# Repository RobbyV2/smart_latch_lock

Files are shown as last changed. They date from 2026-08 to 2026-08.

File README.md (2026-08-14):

# Folding-Arc Bike Lock

A self-closing bike lock built as a clamshell ring. A fixed arc bolts to the housing, a hinged arc swings 180 degrees to meet it, and a worm gearmotor closes the loop around the frame and rim on a button press or a BLE command. A spring latch pin seats with power off, a keyed cam lock covers a dead battery, and an ESP32-C3 on a 4-layer PCB runs the state machine.

<table>
<tr>
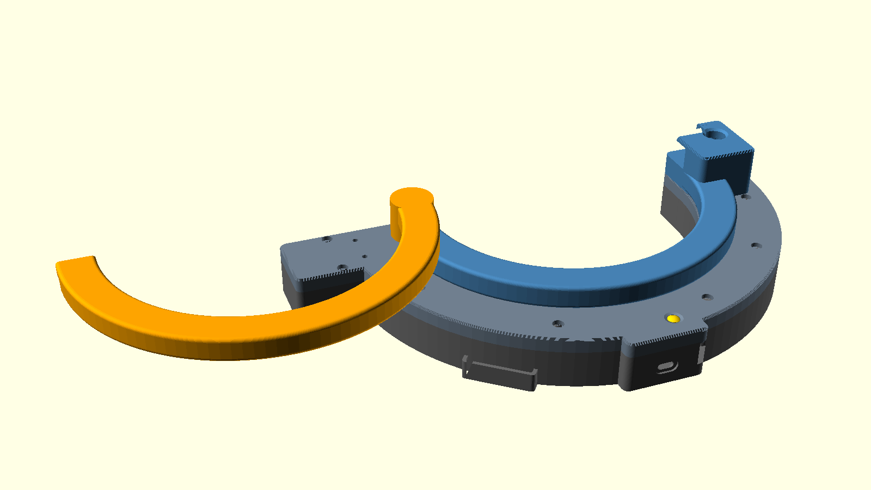
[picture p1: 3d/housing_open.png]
Housing with the swing arc folded open and the latch pin retracted
<td></td>
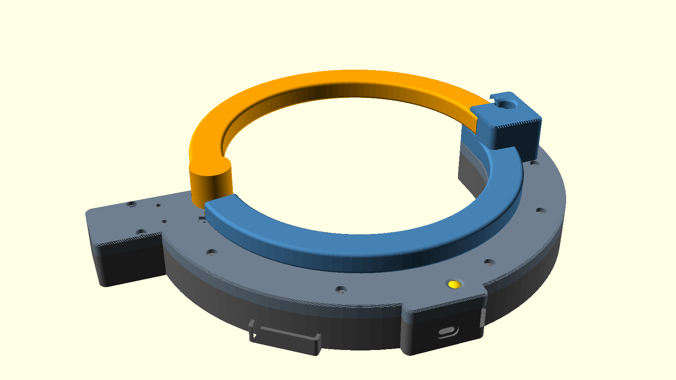
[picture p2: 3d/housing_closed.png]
Housing with the swing arc closed and the latch pin seated
<td></td>
</tr>
</table>

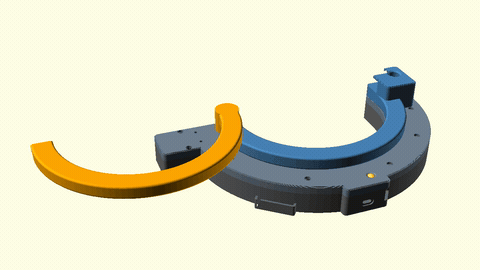
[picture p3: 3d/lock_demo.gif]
Animated lock cycle


The animation shows one closing cycle: the swing arc starts folded open and sweeps around until it seats in the receiver at the fixed arc tip.

<table>
<tr>
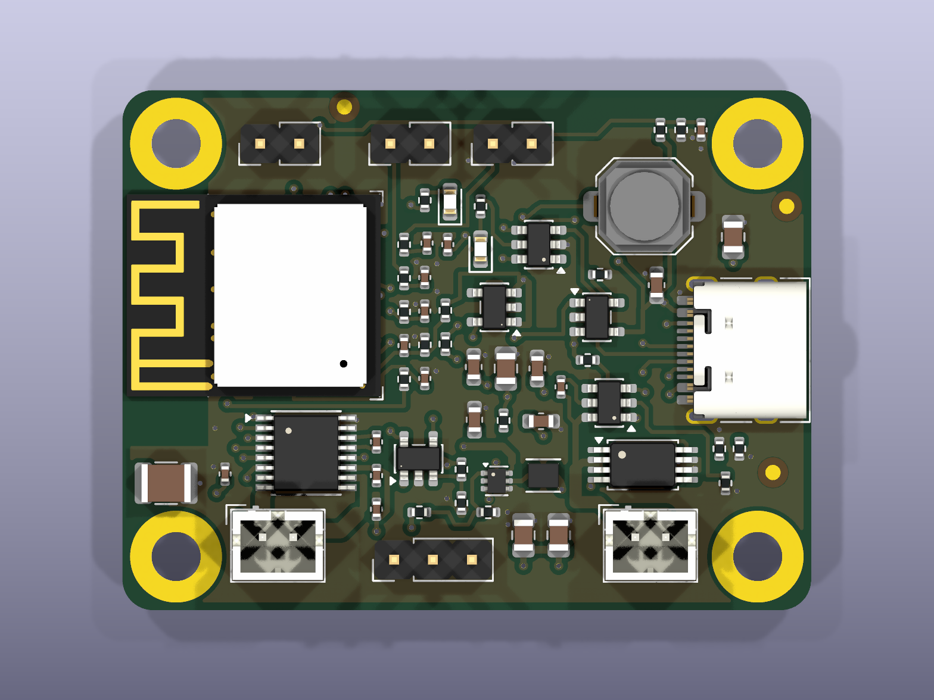
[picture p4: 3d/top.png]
Top view of the board
<td></td>
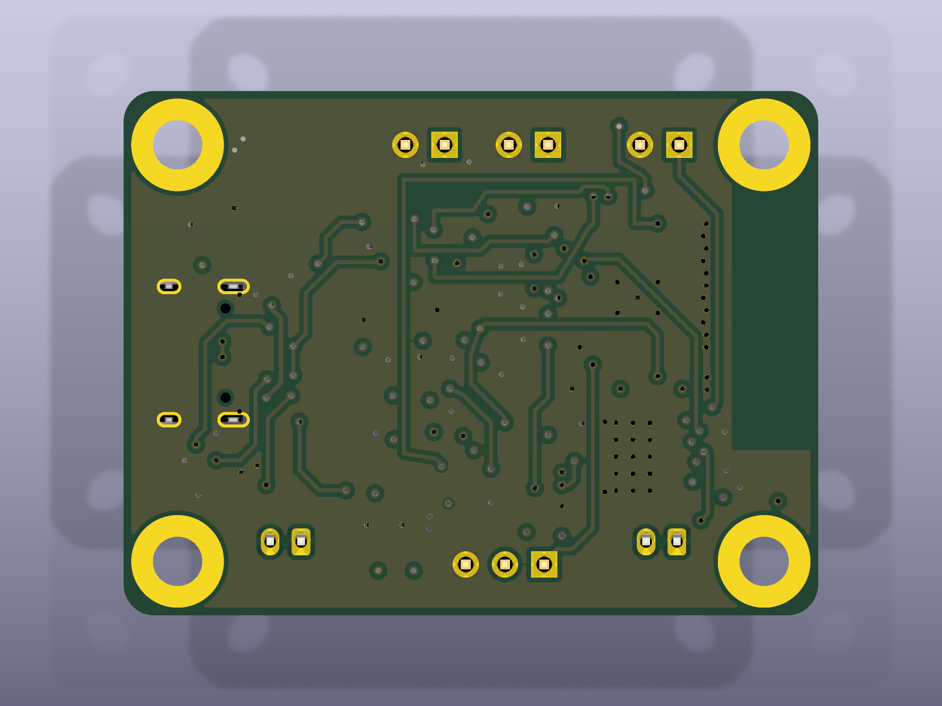
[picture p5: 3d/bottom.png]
Bottom view of the board
<td></td>
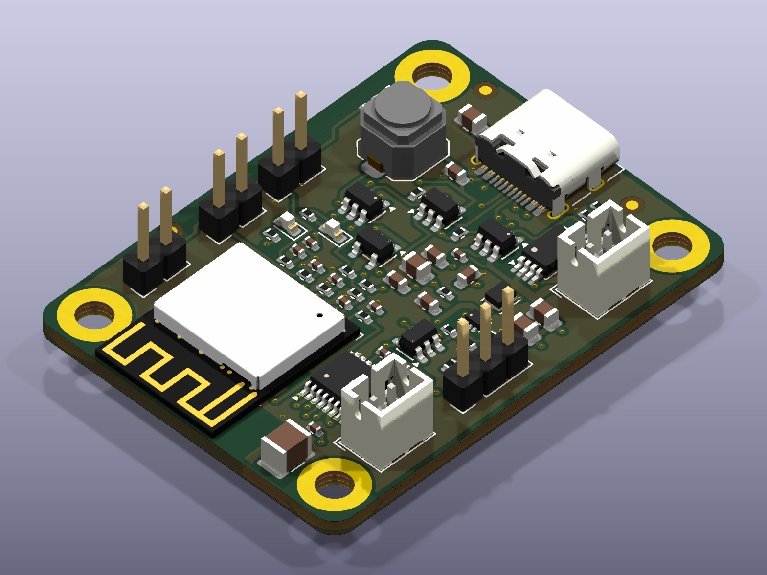
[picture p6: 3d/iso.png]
Angled view of the board
<td></td>
</tr>
</table>

Read `docs/design.md` for the mechanism, the torque analysis, and the electronics.

## Repository layout

- `hw/` holds the KiCad schematic, the board, the design rules, and the stack manifest.
- `lib/` holds the symbols, the footprints, and the 3D models.
- `firmware/` holds the PlatformIO project for the ESP32-C3.
- `3d/` holds the OpenSCAD housing, the board render script, and the renders.
- `scripts/` holds the release script and the validation scripts.
- `fab/` holds the fabrication data, written by `scripts/release.sh`.

## Build

```
pio run -d firmware
openscad -o temp/arc_swing.stl -D 'part="arc_swing"' 3d/housing.scad
python3 3d/build.py
scripts/release.sh hw/triangle_flywheel_balancer.kicad_pcb
```

The first command builds the firmware, the second renders one housing part (`housing_inner`, `housing_lid`, `arc_fixed`, `arc_swing`, `latch_pin`, `assembly`), the third writes the board renders and the viewer page, and the fourth writes the fabrication tree.

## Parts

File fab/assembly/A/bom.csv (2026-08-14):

Designator | Quantity | Manufacturer | MPN | Value | Footprint | LCSC Part #
C1,C7,C8 | 3 | Samsung Electro-Mechanics | CL10A105KB8NNNC | 1uF | triangle_flywheel_balancer:C_0603_1608Metric | C15849
C10,C11 | 2 | Samsung Electro-Mechanics | CL21A226MAQNNNE | 22uF | triangle_flywheel_balancer:C_0805_2012Metric | C45783
C12,C14,C17,C18,C19,C20,C21,C22,C3,C6 | 10 | Samsung Electro-Mechanics | CL05B104KO5NNNC | 100nF | triangle_flywheel_balancer:C_0402_1005Metric | C1525
C13 | 1 | Samsung Electro-Mechanics | CL32A107MPVNNNE | 100uF | triangle_flywheel_balancer:C_1210_3225Metric | C23742
C15 | 1 | Samsung Electro-Mechanics | CL05B223KB5NNNC | 22nF | triangle_flywheel_balancer:C_0402_1005Metric | C337699
C16 | 1 | FH | 0402B102K500NT | 1nF | triangle_flywheel_balancer:C_0402_1005Metric | C1523
C2,C9 | 2 | Samsung Electro-Mechanics | CL21A106KAYNNNE | 10uF | triangle_flywheel_balancer:C_0805_2012Metric | C15850
C4,C5 | 2 | Samsung Electro-Mechanics | CL10A475KO8NNNC | 4.7uF | triangle_flywheel_balancer:C_0603_1608Metric | C19666
D1 | 1 | STMicroelectronics | USBLC6-2SC6 | USBLC6-2SC6 | triangle_flywheel_balancer:SOT-23-6 | C7519
D2,D3 | 2 | Hubei KENTO | KT-0603R | LED | triangle_flywheel_balancer:LED_0603_1608Metric | C2286
J1 | 1 | Korean Hroparts | TYPE-C-31-M-12 | TYPE-C-31-M-12 | triangle_flywheel_balancer:USB_C_Receptacle_HRO_TYPE-C-31-M-12 | C165948
J2 | 1 | JST | B2B-PH-K-S(LF)(SN) | BATTERY | triangle_flywheel_balancer:JST_PH_B2B-PH-K_1x02_P2.00mm_Vertical | C131337
J3 | 1 | JST | B2B-PH-K-S(LF)(SN) | MOTOR | triangle_flywheel_balancer:JST_PH_B2B-PH-K_1x02_P2.00mm_Vertical | C131337
J4 | 1 | BOOMELE | 2.54-1*3P | SERVO | triangle_flywheel_balancer:PinHeader_1x03_P2.54mm_Vertical | C49257
J5 | 1 | Ckmtw | B-2100S02P-A110 | LATCH | triangle_flywheel_balancer:PinHeader_1x02_P2.54mm_Vertical | C124375
J6 | 1 | Ckmtw | B-2100S02P-A110 | OPEN | triangle_flywheel_balancer:PinHeader_1x02_P2.54mm_Vertical | C124375
J7 | 1 | Ckmtw | B-2100S02P-A110 | CLOSED | triangle_flywheel_balancer:PinHeader_1x02_P2.54mm_Vertical | C124375
L1 | 1 | Murata | DFE201610E-1R0M=P2 | 1uH | triangle_flywheel_balancer:L_Murata_DFE201610P | C161082
Q1 | 1 | HXY MOSFET | 8205A | FS8205A | triangle_flywheel_balancer:TSSOP-8_4.4x3mm_P0.65mm | C5148694
R1 | 1 | YAGEO | RC0402FR-0710KL | 10k | triangle_flywheel_balancer:R_0402_1005Metric | C60490
R10,R14,R17,R18,R19,R4,R7 | 7 | UNI-ROYAL | 0402WGF1001TCE | 1k | triangle_flywheel_balancer:R_0402_1005Metric | C11702
R11 | 1 | UNI-ROYAL | 0402WGF3302TCE | 33k | triangle_flywheel_balancer:R_0402_1005Metric | C25779
R12 | 1 | UNI-ROYAL | 0402WGF5102TCE | 51k | triangle_flywheel_balancer:R_0402_1005Metric | C25794
R13,R15,R16,R21 | 4 | UNI-ROYAL | 0402WGF1003TCE | 100k | triangle_flywheel_balancer:R_0402_1005Metric | C25741
R2,R3 | 2 | UNI-ROYAL | 0402WGF5101TCE | 5.1k | triangle_flywheel_balancer:R_0402_1005Metric | C25905
R20 | 1 | PANASONIC | ERJ2RKF6802X | 68k | triangle_flywheel_balancer:R_0402_1005Metric | C77607
R5 | 1 | YAGEO | RC0402FR-072KL | 2k | triangle_flywheel_balancer:R_0402_1005Metric | C60488
R6 | 1 | UNI-ROYAL | 0402WGF3300TCE | 330 | triangle_flywheel_balancer:R_0402_1005Metric | C25104
R8 | 1 | UNI-ROYAL | 0402WGF1103TCE | 110k | triangle_flywheel_balancer:R_0402_1005Metric | C25745
R9 | 1 | UNI-ROYAL | 0402WGF1502TCE | 15k | triangle_flywheel_balancer:R_0402_1005Metric | C25756
S4 | 1 | XKB | TS-1187A-B-A-B | SW_Push | triangle_flywheel_balancer:SW_Push_1TS009xxxx-xxxx-xxxx_6x6x5mm | C318884
U1 | 1 | Espressif | ESP32-C3-MINI-1-N4 | ESP32-C3-MINI-1-N4 | triangle_flywheel_balancer:ESP32-C3-MINI-1 | C2838502
U2 | 1 | Texas Instruments | DRV8876PWPR | DRV8876PWPR | triangle_flywheel_balancer:HTSSOP-16-1EP_4.4x5mm_P0.65mm_EP3.4x5mm_Mask3x3mm_ThermalVias | C575551
U3 | 1 | Texas Instruments | TLV1701AIDBVR | TLV1701AIDBVR | triangle_flywheel_balancer:SOT-23-5 | C130035
U4 | 1 | Microchip | MCP73831T-2ACI/OT | MCP73831T-2ACI/OT | triangle_flywheel_balancer:SOT-23-5 | C424093
U5 | 1 | PUOLOP | DW01A | DW01A | triangle_flywheel_balancer:SOT-23-6 | C351410
U6 | 1 | Torex | XC6220B331MR-G | XC6220B331MR-G | triangle_flywheel_balancer:SOT-23-5 | C86534
U7 | 1 | Texas Instruments | TPS61023DRLR | TPS61023DRLR | triangle_flywheel_balancer:SOT-563 | C919459

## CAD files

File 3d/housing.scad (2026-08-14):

part = "assembly";
swing = 0; // 0 closed, 180 folded open
pin_lift = 0; // 0 seated, 3 retracted

enclosed_dia = 160; // valid 120-220
arc_w = 20;
arc_t = 13;
wall = 2.5;
clr = 0.25;

jgy_gear = [46, 32, 25];
jgy_motor_d = 24.4;
jgy_motor_l = 30.8;
jgy_shaft_d = 6;
jgy_shaft_l = 14;
jgy_shaft_flat = 2.55;
jgy_shaft_from_end = 9;
jgy_mount_dx = 33; jgy_mount_dy = 18;

pcb = [45, 34, 1.6];
pcb_standoff = 5;
bat = [34, 50, 11];
d2f = [12.8, 5.8, 6.5];
d2f_hole_pitch = 6.5;
servo_cav = [24, 13.5, 26];
pin_d = 5;
collar_d = 9;
camlock_d = 12;
spring_d = 9.5;
btn_d = 6.5;

Ri = enclosed_dia/2;
Rc = Ri + arc_w/2;
Ro = Ri + arc_w;
hx = -Rc;
house_or = Ro + 26;
floor_t = wall;
H = floor_t + jgy_gear[2] + wall;
seam = H - 8;
za0 = H;
za1 = H + arc_t;
zs0 = za1;
zs1 = za1 + arc_t;
zpin = zs0 + arc_t/2;
rec_x0 = Ri; rec_x1 = Ro + 16;
rec_y0 = -20; rec_y1 = 22;
rec_top = zs1 + 3;
fixed_a0 = 190;
boss_d = 24;
lobe_x0 = -(Rc + jgy_gear[0] - jgy_shaft_from_end + jgy_motor_l + 4);
lobe_hw = jgy_gear[1]/2 + clr + wall + 1;

boss_pts = [for (a=[205,245,288,320,348]) (Ri+33)*[cos(a),sin(a)]];
lobe_boss = [[-Rc-45, 15.5], [-Rc-45, -15.5]];
screw_pts = concat(boss_pts, lobe_boss);

$fa = 3; $fs = 0.5;

module ring(r0, r1, h, a0, a1, round_r=0)
  rotate([0,0,a0]) rotate_extrude(angle=a1-a0)
    translate([r0,0]) offset(round_r) offset(-round_r) square([r1-r0, h]);

module rbox(x0, x1, y0, y1, r=4)
  offset(r) offset(-r) translate([x0,y0]) square([x1-x0, y1-y0]);

module chamfered(h, cb=0, ct=0, n=5) { // stepped edge chamfer on 2D child
  translate([0,0,cb]) linear_extrude(h - cb - ct) children();
  for (i=[0:n-1]) {
    if (cb > 0) translate([0,0,cb*i/n]) linear_extrude(cb/n + 0.02)
      offset(-cb*(n-i)/n) children();
    if (ct > 0) translate([0,0,h - ct*(n-i)/n - 0.02]) linear_extrude(ct/n + 0.02)
      offset(-ct*(i+1)/n) children();
  }
}

module plan2d() offset(2) offset(-2) union() {
  difference() {
    circle(house_or);
    circle(Ri);
    translate([-2*house_or, 1]) square([4*house_or, 2*house_or]);
  }
  rbox(lobe_x0, -Ri, -lobe_hw, lobe_hw);
  rbox(rec_x0, rec_x1, rec_y0, rec_y1);
  rbox(-pcb[1]/2 - 6, pcb[1]/2 + 6, pcb_wall_y, -Ri - 15); // flat wall bump clears PCB corners
}

module cavity2d() offset(-wall) plan2d();

module motor_void() {
  gx1 = -(Rc - jgy_shaft_from_end);
  translate([gx1 - jgy_gear[0] - clr, -jgy_gear[1]/2 - clr, floor_t])
    cube([jgy_gear[0] + 2*clr, jgy_gear[1] + 2*clr, jgy_gear[2] + clr]);
  translate([gx1 - jgy_gear[0], 0, floor_t + jgy_gear[2]/2])
    rotate([0,-90,0]) cylinder(d=jgy_motor_d + 2*clr, h=jgy_motor_l + 2);
}

module d2f_pocket(depth)
  translate([0,0,-depth]) {
    translate([-d2f[0]/2 - clr, -d2f[1]/2 - clr]) cube([d2f[0]+2*clr, d2f[1]+2*clr, depth+2*arc_t]);
    for (s=[-1,1]) translate([s*d2f_hole_pitch/2, 0, -6]) cylinder(d=1.9, h=6.1);
  }

pcb_c = [0, -(Ri + wall + pcb[0]/2 + 1)]; // long board axis along y, x=45 edge at the flat wall
function bd(p) = pcb_c + [pcb[1]/2 - p[1], pcb[0]/2 - p[0]]; // board (x right, y down) to housing
pcb_wall_y = pcb_c[1] - pcb[0]/2 - 0.3 - wall;
pcb_holes = [for (p=[[3.5,3.5],[41.5,3.5],[3.5,30.5],[41.5,30.5]]) bd(p)];
pcb_top = floor_t + pcb_standoff + pcb[2];
usb_c = bd([pcb[0], 17]);
usb_z = pcb_top + 1.9;
btn_c = bd([34.1, 7.6]);
btn_z = pcb_top + 5; // S4 plunger top
lid_in = H - wall;
btn_lift = 0.2; // free travel to the lid
btn_stem = lid_in - btn_z - btn_lift - 1.2;

module wall_slot(w, h, d) // rounded slot through the flat PCB wall
  translate([usb_c[0], pcb_wall_y - 1, usb_z]) rotate([-90,0,0])
    hull() for (s=[-1,1]) translate([s*(w-h)/2, 0, 0]) cylinder(d=h, h=d);

module button_cap() {
  cylinder(d=3.4, h=btn_stem);
  translate([0,0,btn_stem]) cylinder(d=9, h=1.2); // retaining flange, fitted from inside
  translate([0,0,btn_stem+1.2]) cylinder(d=btn_d, h=H - 0.6 - btn_z - btn_stem - 1.2);
  intersection() {
    translate([0,0,H - 0.6 - btn_z - 4.3]) sphere(r=5.4);
    translate([0,0,H - 0.6 - btn_z]) cylinder(d=btn_d, h=1.1);
  }
}

module btn_place() translate([btn_c[0], btn_c[1], btn_z]) children();

module button_bore() translate([btn_c[0], btn_c[1], 0]) {
  translate([0,0,lid_in - 0.5]) cylinder(d=btn_d + 0.3, h=wall + 0.51);
  translate([0,0,H - 0.6]) cylinder(d1=btn_d + 0.3, d2=btn_d + 3.3, h=0.61); // bezel
}

module housing_inner() difference() {
  union() {
    difference() {
      chamfered(seam, cb=1) plan2d();
      translate([0,0,floor_t]) linear_extrude(seam) cavity2d();
    }
    for (p=pcb_holes) translate([p[0], p[1], 0]) cylinder(d=5.5, h=floor_t+pcb_standoff);
    rotate([0,0,232]) translate([Ri+23, 0, 0]) rotate([0,0,-90])
      linear_extrude(floor_t + 8) difference() {
        rbox(-bat[0]/2-clr-2, bat[0]/2+clr+2, -bat[1]/2-clr-2, bat[1]/2+clr+2, 2);
        rbox(-bat[0]/2-clr, bat[0]/2+clr, -bat[1]/2-clr-3, bat[1]/2+clr, 1);
      }
    for (p=screw_pts) translate([p[0], p[1], 0]) cylinder(d=6.5, h=seam);
  }
  motor_void();
  translate([0,0,seam-1.6]) linear_extrude(3) difference()
    { offset(-0.6) plan2d(); offset(-1.9) plan2d(); }
  for (p=pcb_holes) translate([p[0], p[1], floor_t]) cylinder(d=2.1, h=pcb_standoff+6);
  for (p=screw_pts) translate([p[0], p[1], 4]) cylinder(d=2.5, h=seam);
  wall_slot(9.04, 3.6, wall + 2);
  wall_slot(13, 7.2, 2.2); // plug body recess
}

pin_y = 6;
slot_x0 = Ro - 0.5; slot_x1 = Ro + 7.5; // collar travel slot
cam_x = Ro + 3.5;
endstop_a = [250, 70]; // closed, open azimuth about hinge

module fixed_arc_solid() {
  translate([0,0,za0]) ring(Ri, Ro, arc_t, fixed_a0, 360, 2);
  translate([0,0,za0]) chamfered(rec_top - za0, ct=1) rbox(rec_x0, rec_x1, rec_y0, rec_y1);
}

module seat_pocket() {
  translate([Ri-0.4, -0.5, zs0-0.4]) cube([arc_w+0.8, rec_y1+1, arc_t+0.8]);
  translate([Ri-0.4, 10, zs0-0.4]) cube([arc_w+0.8, rec_y1, rec_top]); // open top past roof
  translate([Ri-6, rec_y1-4, zs0+2]) rotate([45,0,0]) cube([arc_w+12, 10, 10]); // roof entry chamfer
}

module latch_bores() {
  translate([Ri+4, pin_y, zpin]) rotate([0,90,0]) cylinder(d=pin_d+0.4, h=rec_x1-Ri-4.5);
  translate([Rc+16, pin_y, zpin]) rotate([0,90,0]) cylinder(d=spring_d+0.3, h=rec_x1-Rc-17);
  translate([slot_x0, pin_y-collar_d/2-0.3, 24]) // collar + servo horn slot
    cube([slot_x1-slot_x0, collar_d+0.6, zpin+collar_d/2+0.3-24]);
  translate([cam_x, pin_y, zpin+2]) cylinder(d=camlock_d+0.3, h=rec_top); // cam lock barrel
  translate([cam_x, pin_y, rec_top-1.3]) cylinder(d1=camlock_d+0.3, d2=camlock_d+3.3, h=1.4); // flush face ring
  translate([Ri+8, pin_y, za0+3]) cube([13.3, 6.3, 6.9], center=true); // latch-sense switch
  translate([Ri+8, (rec_y0+pin_y)/2, za0+3]) cube([6.3, pin_y-rec_y0, 6.9], center=true);
  translate([Ri+8, pin_y, za0+5]) cylinder(d=2, h=zs0-za0-4.5); // plunger to seat floor
  translate([Ri+8, pin_y, 20]) cylinder(d=3, h=za0-19); // switch wire drop
}

module servo_void()
  translate([Rc+8 - servo_cav[0]/2, pin_y - servo_cav[1]/2, seam-1])
    cube(servo_cav);

gearbox_cx = -(Rc - jgy_shaft_from_end) - jgy_gear[0]/2;

module housing_lid(arc=true) difference() {
  union() {
    difference() {
      chamfered(H - seam, ct=1) plan2d();
      translate([0,0,-1]) linear_extrude(H - seam - wall + 1) cavity2d();
    }
    translate([0,0,-1.4]) linear_extrude(1.4) difference()
      { offset(-0.75) plan2d(); offset(-1.75) plan2d(); }
    if (arc) translate([0,0,-seam]) fixed_arc_solid();
    translate([hx, 0, H - seam]) cylinder(d=11, h=3);
  }
  translate([hx, 0, -2]) cylinder(d=jgy_shaft_d + 0.6, h=H - seam + 5.5);
  for (sx=[-1,1], sy=[-1,1])
    translate([gearbox_cx + sx*jgy_mount_dx/2, sy*jgy_mount_dy/2, -1])
      cylinder(d=3.2, h=H - seam + 2);
  for (p=screw_pts) translate([p[0], p[1], -2]) {
    cylinder(d=3.2, h=H - seam + 4);
    translate([0,0,2 + H - seam - 2.5]) cylinder(d=6.2, h=40);
  }
  for (i=[0,1]) let(a=endstop_a[i])
    translate([hx + 17*cos(a), 17*sin(a), H - seam]) rotate([0,0,a+90]) d2f_pocket(2);
  translate([0,0,-seam]) {
    seat_pocket();
    latch_bores();
    servo_void();
    motor_void();
    button_bore();
  }
}

module arc_swing_solid() {
  translate([0,0,zs0]) ring(Ri, Ro, arc_t, 0, 180, 2);
  translate([hx, 0, H+3.5]) cylinder(d=boss_d, h=zs1 - H - 3.5);
  translate([hx, 0, H+3.5]) rotate([0,0,endstop_a[0]])
    translate([boss_d/2 - 2, -2.5, 0]) cube([18 - boss_d/2 + 2, 5, 3]);
}

module arc_swing() difference() {
  arc_swing_solid();
  translate([hx, 0, H+3.4]) linear_extrude(42 - H - 3.4) difference() {
    circle(d=jgy_shaft_d + 0.15);
    translate([jgy_shaft_flat, -5]) square(10);
  }
  translate([hx, 0, 38]) rotate([0,-90,0]) cylinder(d=2.6, h=boss_d/2 + 2);
  translate([0,0,zpin]) rotate([0,0,-2]) rotate_extrude(angle=170)
    translate([Rc,0]) circle(d=6.2);
  translate([Ro+2, 2, zs0-1]) rotate([0,0,45]) cube([14,14,arc_t+2], center=true);
  translate([Rc+3, pin_y, zpin]) rotate([0,90,0]) cylinder(d=pin_d+0.4, h=arc_w/2+3);
}
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

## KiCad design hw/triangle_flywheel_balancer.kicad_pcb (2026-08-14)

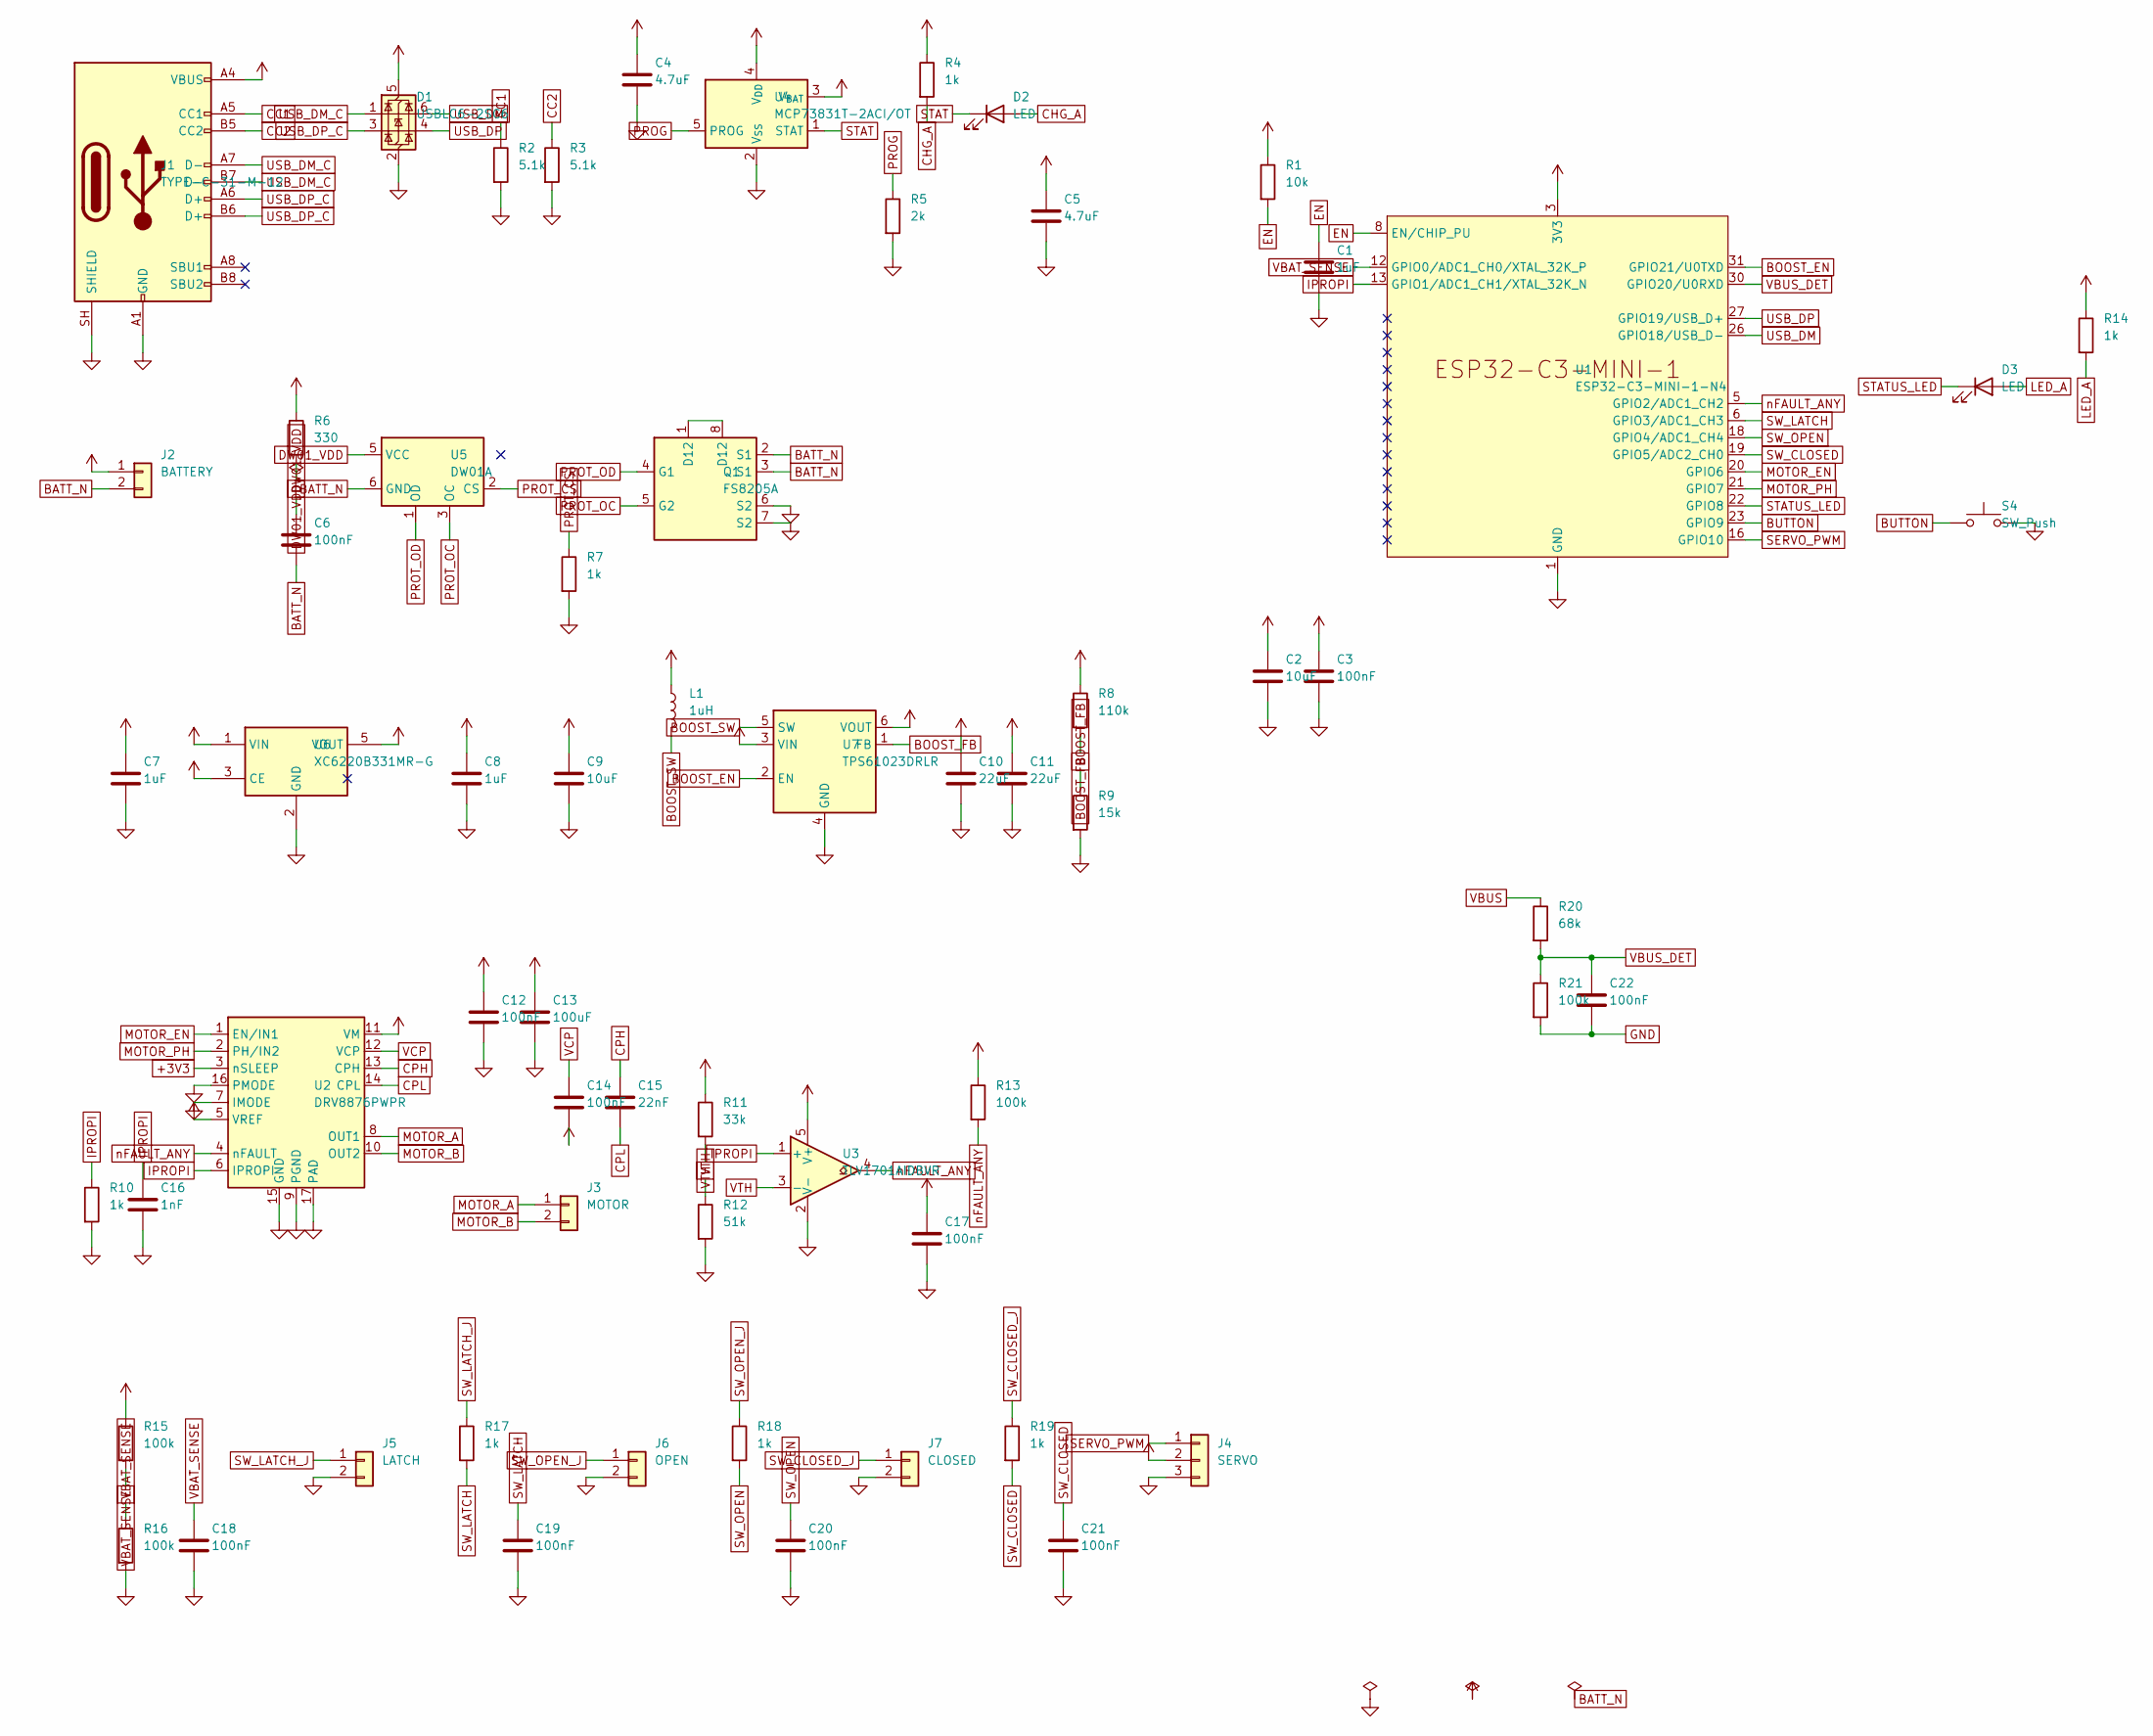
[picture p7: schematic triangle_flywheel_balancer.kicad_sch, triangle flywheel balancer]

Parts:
C1, C7, C8: 1uF; C_0603_1608Metric; MPN CL10A105KB8NNNC; LCSC Part C15849
C2, C9: 10uF; C_0805_2012Metric; MPN CL21A106KAYNNNE; LCSC Part C15850
C3, C6, C12, C14, C17, C18, C19, C20, C21, C22: 100nF; C_0402_1005Metric; MPN CL05B104KO5NNNC; LCSC Part C1525
C4, C5: 4.7uF; C_0603_1608Metric; MPN CL10A475KO8NNNC; LCSC Part C19666
C10, C11: 22uF; C_0805_2012Metric; MPN CL21A226MAQNNNE; LCSC Part C45783
C13: 100uF; C_1210_3225Metric; MPN CL32A107MPVNNNE; LCSC Part C23742
C15: 22nF; C_0402_1005Metric; MPN CL05B223KB5NNNC; LCSC Part C337699
C16: 1nF; C_0402_1005Metric; MPN 0402B102K500NT; LCSC Part C1523
D1: USBLC6-2SC6; SOT-23-6; MPN USBLC6-2SC6; LCSC Part C7519
D2, D3: LED; LED_0603_1608Metric; MPN KT-0603R; LCSC Part C2286
J1: TYPE-C-31-M-12; USB_C_Receptacle_HRO_TYPE-C-31-M-12; MPN TYPE-C-31-M-12; LCSC Part C165948
J2: BATTERY; JST_PH_B2B-PH-K_1x02_P2.00mm_Vertical; MPN B2B-PH-K-S(LF)(SN); LCSC Part C131337
J3: MOTOR; JST_PH_B2B-PH-K_1x02_P2.00mm_Vertical; MPN B2B-PH-K-S(LF)(SN); LCSC Part C131337
J4: SERVO; PinHeader_1x03_P2.54mm_Vertical; MPN 2.54-1*3P; LCSC Part C49257
J5: LATCH; PinHeader_1x02_P2.54mm_Vertical; MPN B-2100S02P-A110; LCSC Part C124375
J6: OPEN; PinHeader_1x02_P2.54mm_Vertical; MPN B-2100S02P-A110; LCSC Part C124375
J7: CLOSED; PinHeader_1x02_P2.54mm_Vertical; MPN B-2100S02P-A110; LCSC Part C124375
L1: 1uH; L_Murata_DFE201610P; MPN DFE201610E-1R0M=P2; LCSC Part C161082
Q1: FS8205A; TSSOP-8_4.4x3mm_P0.65mm; MPN 8205A; LCSC Part C5148694
R1: 10k; R_0402_1005Metric; MPN RC0402FR-0710KL; LCSC Part C60490
R2, R3: 5.1k; R_0402_1005Metric; MPN 0402WGF5101TCE; LCSC Part C25905
R4, R7, R10, R14, R17, R18, R19: 1k; R_0402_1005Metric; MPN 0402WGF1001TCE; LCSC Part C11702
R5: 2k; R_0402_1005Metric; MPN RC0402FR-072KL; LCSC Part C60488
R6: 330; R_0402_1005Metric; MPN 0402WGF3300TCE; LCSC Part C25104
R8: 110k; R_0402_1005Metric; MPN 0402WGF1103TCE; LCSC Part C25745
R9: 15k; R_0402_1005Metric; MPN 0402WGF1502TCE; LCSC Part C25756
R11: 33k; R_0402_1005Metric; MPN 0402WGF3302TCE; LCSC Part C25779
R12: 51k; R_0402_1005Metric; MPN 0402WGF5102TCE; LCSC Part C25794
R13, R15, R16, R21: 100k; R_0402_1005Metric; MPN 0402WGF1003TCE; LCSC Part C25741
R20: 68k; R_0402_1005Metric; MPN ERJ2RKF6802X; LCSC Part C77607
S4: SW_Push; SW_Push_1TS009xxxx-xxxx-xxxx_6x6x5mm; MPN TS-1187A-B-A-B; LCSC Part C318884
U1: ESP32-C3-MINI-1-N4; ESP32-C3-MINI-1; MPN ESP32-C3-MINI-1-N4; LCSC Part C2838502
U2: DRV8876PWPR; HTSSOP-16-1EP_4.4x5mm_P0.65mm_EP3.4x5mm_Mask3x3mm_ThermalVi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; MPN DRV8876PWPR; LCSC Part C575551
U3: TLV1701AIDBVR; SOT-23-5; MPN TLV1701AIDBVR; LCSC Part C130035
U4: MCP73831T-2ACI/OT; SOT-23-5; MPN MCP73831T-2ACI/OT; LCSC Part C424093
U5: DW01A; SOT-23-6; MPN DW01A; LCSC Part C351410
U6: XC6220B331MR-G; SOT-23-5; MPN XC6220B331MR-G; LCSC Part C86534
U7: TPS61023DRLR; SOT-563; MPN TPS61023DRLR; LCSC Part C919459

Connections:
+3V3: C2.1, C3.1, C8.1, C17.1, R1.1, R11.1, R13.1, R14.1, U1.3 (3V3), U2.3 (nSLEEP), U2.5 (VREF), U3.5 (V+), U6.5 (VOUT)
+5V: C10.1, C11.1, C12.1, C13.1, C14.2, J4.2, R8.1, U2.11 (VM), U7.6 (VOUT)
BATT_N: C6.2, J2.2, Q1.2 (S1), Q1.3 (S1), U5.6 (GND)
BOOST_EN: U1.31 (GPIO21/U0TXD), U7.2 (EN)
BOOST_FB: R8.2, R9.1, U7.1 (FB)
BOOST_SW: L1.2, U7.5 (SW)
BUTTON: S4.1, U1.23 (GPIO9)
CC1: J1.A5 (CC1), R2.1
CC2: J1.B5 (CC2), R3.1
CHG_A: D2.2 (A), R4.2
CPH: C15.1, U2.13 (CPH)
CPL: C15.2, U2.14 (CPL)
DW01_VDD: C6.1, R6.2, U5.5 (VCC)
EN: C1.1, R1.2, U1.8 (EN/CHIP_PU)
GND: C1.2, C2.2, C3.2, C4.2, C5.2, C7.2, C8.2, C9.2, C10.2, C11.2, C12.2, C13.2, C16.2, C17.2, C18.2, C19.2, C20.2, C21.2, C22.2, D1.2 (GND), J1.A1 (GND), J1.A12 (GND), J1.B1 (GND), J1.B12 (GND), J1.SH (SHIELD), J4.3, J5.2, J6.2, J7.2, Q1.6 (S2), Q1.7 (S2), R2.2, R3.2, R5.2, R7.2, R9.2, R10.2, R12.2, R16.2, R21.2, S4.2, U1.1 (GND), U1.2 (GND), U1.11 (GND), U1.14 (GND), U1.36 (GND), U1.37 (GND), U1.38 (GND), U1.39 (GND), U1.40 (GND), U1.41 (GND), U1.42 (GND), U1.43 (GND), U1.44 (GND), U1.45 (GND), U1.46 (GND), U1.47 (GND), U1.48 (GND), U1.49 (GND), U1.50 (GND), U1.51 (GND), U1.52 (GND), U1.53 (GND), U2.7 (IMODE), U2.9 (PGND), U2.15 (GND), U2.16 (PMODE), U2.17 (PAD), U3.2 (V-), U4.2 (V_{SS}), U6.2 (GND), U7.4 (GND)
IPROPI: C16.1, R10.1, U1.13 (GPIO1/ADC1_CH1/XTAL_32K_N), U2.6 (IPROPI), U3.1 (+)
LED_A: D3.2 (A), R14.2
MOTOR_A: J3.1, U2.8 (OUT1)
MOTOR_B: J3.2, U2.10 (OUT2)
MOTOR_EN: U1.20 (GPIO6), U2.1 (EN/IN1)
MOTOR_PH: U1.21 (GPIO7), U2.2 (PH/IN2)
unnamed: Q1.1 (D12), Q1.8 (D12)
PROG: R5.1, U4.5 (PROG)
PROT_CS: R7.1, U5.2 (CS)
PROT_OC: Q1.5 (G2), U5.3 (OC)
PROT_OD: Q1.4 (G1), U5.1 (OD)
SERVO_PWM: J4.1, U1.16 (GPIO10)
STAT: D2.1 (K), U4.1 (STAT)
STATUS_LED: D3.1 (K), U1.22 (GPIO8)
SW_CLOSED: C21.1, R19.2, U1.19 (GPIO5/ADC2_CH0)
SW_CLOSED_J: J7.1, R19.1
SW_LATCH: C19.1, R17.2, U1.6 (GPIO3/ADC1_CH3)
SW_LATCH_J: J5.1, R17.1
SW_OPEN: C20.1, R18.2, U1.18 (GPIO4/ADC1_CH4)
SW_OPEN_J: J6.1, R18.1
USB_DM: D1.6 (I/O1), U1.26 (GPIO18/USB_D-)
USB_DM_C: D1.1 (I/O1), J1.A7 (D-), J1.B7 (D-)
USB_DP: D1.4 (I/O2), U1.27 (GPIO19/USB_D+)
USB_DP_C: D1.3 (I/O2), J1.A6 (D+), J1.B6 (D+)
VBAT: C5.1, C7.1, C9.1, J2.1, L1.1, R6.1, R15.1, U4.3 (V_{BAT}), U6.1 (VIN), U6.3 (CE), U7.3 (VIN)
VBAT_SENSE: C18.1, R15.2, R16.1, U1.12 (GPIO0/ADC1_CH0/XTAL_32K_P)
VBUS: C4.1, D1.5 (VBUS), J1.A4 (VBUS), J1.A9 (VBUS), J1.B4 (VBUS), J1.B9 (VBUS), R4.1, R20.1, U4.4 (V_{DD})
VBUS_DET: C22.1, R20.2, R21.1, U1.30 (GPIO20/U0RXD)
VCP: C14.1, U2.12 (VCP)
VTH: R11.2, R12.1, U3.3 (-)
nFAULT_ANY: R13.2, U1.5 (GPIO2/ADC1_CH2), U2.4 (nFAULT), U3.4

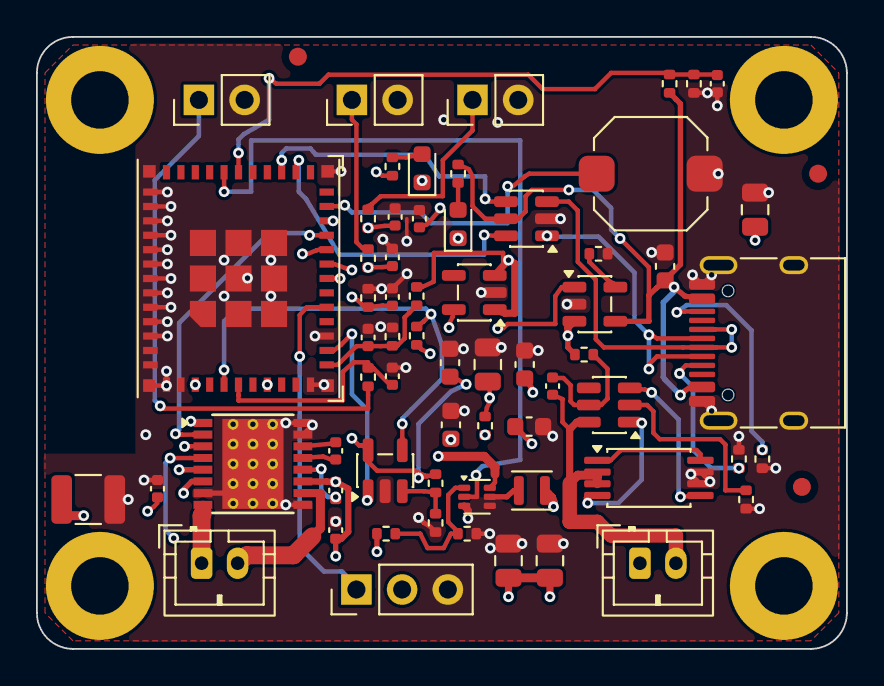
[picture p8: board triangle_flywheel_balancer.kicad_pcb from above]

Board: 4 copper layers, 45.0 x 34.0 mm, 70 parts (0 on the bottom side), 46 nets.

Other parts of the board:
FID1, FID2, FID3: Fiducial; Fiducial_1mm_Mask2mm
H1, H2, H3, H4: MountingHole; MountingHole_3.2mm_M2.5

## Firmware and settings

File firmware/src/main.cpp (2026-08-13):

#include <Arduino.h>
#include <driver/gpio.h>
#include "pins.h"
#include "motor.h"
#include "lock.h"
#include "ble.h"
#include "web.h"

void setup() {
  Serial.begin(115200);
  setCpuFrequencyMhz(80);
  gpio_install_isr_service(ESP_INTR_FLAG_IRAM);
  pinMode(PIN_BUTTON, INPUT_PULLUP);
  motorInit();
  bleInit();
  webInit();
  lockInit();
  vTaskDelete(nullptr);
}

void loop() {}

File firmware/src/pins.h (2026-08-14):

#pragma once
#include <stdint.h>

constexpr int PIN_VBAT_SENSE = 0;
constexpr int PIN_IPROPI = 1;
constexpr int PIN_NFAULT = 2;
constexpr int PIN_SW_LATCH = 3;
constexpr int PIN_SW_OPEN = 4;
constexpr int PIN_SW_CLOSED = 5;
constexpr int PIN_MOTOR_EN = 6;
constexpr int PIN_MOTOR_PH = 7;
constexpr int PIN_LED = 8;
constexpr int PIN_BUTTON = 9;
constexpr int PIN_SERVO = 10;
constexpr int PIN_VBUS_DET = 20;
constexpr int PIN_BOOST_EN = 21;

constexpr uint32_t INRUSH_MASK_US = 120000;
constexpr uint32_t MOTOR_TIMEOUT_MS = 3000;
constexpr uint32_t LATCH_TIMEOUT_MS = 500;
constexpr uint32_t UNLATCH_TIMEOUT_MS = 300;
constexpr uint32_t BTN_HOLD_MS = 3000;
constexpr uint32_t BLE_GRACE_MS = 5000;
constexpr int SOFT_STALL_MV = 1200;
constexpr int SOFT_STALL_SAMPLES = 20;
constexpr int VBAT_MIN_LOCK_MV = 3300;
constexpr uint32_t SERVO_RETRACT_US = 1000;
constexpr uint32_t SERVO_RELEASE_US = 2000;
constexpr uint32_t BOOST_OFF_MS = 50;

constexpr char UUID_SVC[] = "8f1d0001-2f3a-4c6e-9b1d-6a0f5e3c7a42";
constexpr char UUID_CMD[] = "8f1d0002-2f3a-4c6e-9b1d-6a0f5e3c7a42";
constexpr char UUID_STATE[] = "8f1d0003-2f3a-4c6e-9b1d-6a0f5e3c7a42";

enum class State : uint8_t {
  UnlockedOpen, Closing, Seating, Locked, Unlatching, Opening, FaultObstructed, FaultTimeout
};
enum class Event : uint8_t {
  CmdLock, CmdUnlock, CmdClear, BtnShort, BtnHold3, EsClosed, EsOpen,
  LatchSeated, LatchClear, Stall, Timeout, Raw
};

constexpr uint8_t F_STALL_HW = 0x01, F_STALL_SOFT = 0x02, F_TIMEOUT = 0x04, F_LATCH = 0x08, F_LOWBAT = 0x10, F_CHARGING = 0x20;

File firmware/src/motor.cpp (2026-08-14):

#include <Arduino.h>
#include <string.h>
#include <driver/gpio.h>
#include <driver/ledc.h>
#include <esp_adc/adc_oneshot.h>
#include <esp_adc/adc_cali.h>
#include <esp_adc/adc_cali_scheme.h>
#include <esp_timer.h>
#include <esp_rom_gpio.h>
#include <soc/gpio_reg.h>
#include <soc/gpio_sig_map.h>
#include <soc/ledc_periph.h>
#include "pins.h"
#include "motor.h"
#include "lock.h"

static constexpr ledc_channel_t CH_MOTOR = LEDC_CHANNEL_0, CH_SERVO = LEDC_CHANNEL_1, CH_LED = LEDC_CHANNEL_2;
static adc_oneshot_unit_handle_t adc;
static adc_cali_handle_t cali;
static esp_timer_handle_t maskTimer, sampleTimer;
static volatile uint8_t faults;
static int win[8], wi, wsum, softCnt;
static bool boost;
static int64_t boostOffAt;
static volatile bool running;
static portMUX_TYPE mux = portMUX_INITIALIZER_UNLOCKED;

static void IRAM_ATTR killPwm() {
  REG_WRITE(GPIO_FUNC0_OUT_SEL_CFG_REG + 4 * PIN_MOTOR_EN, SIG_GPIO_OUT_IDX);
  REG_WRITE(GPIO_OUT_W1TC_REG, 1u << PIN_MOTOR_EN);
}

static void IRAM_ATTR faultIsr(void*) {
  killPwm();
  faults |= F_STALL_HW;
  lockPostFromISR(Event::Stall);
}

static void maskCb(void*) {
  portENTER_CRITICAL(&mux);
  bool r = running && !esp_timer_is_active(maskTimer);
  if (r) {
    REG_WRITE(GPIO_STATUS_W1TC_REG, 1u << PIN_NFAULT);
    gpio_intr_enable((gpio_num_t)PIN_NFAULT);
  }
  portEXIT_CRITICAL(&mux);
  if (r) esp_timer_start_periodic(sampleTimer, 1000);
}

static int adcMv(adc_channel_t ch) {
  int raw = 0, mv = 0;
  adc_oneshot_read(adc, ch, &raw);
  adc_cali_raw_to_voltage(cali, raw, &mv);
  return mv;
}

static void sampleCb(void*) {
  int mv = adcMv(ADC_CHANNEL_1);
  wsum += mv - win[wi];
  win[wi] = mv;
  wi = (wi + 1) & 7;
  if (wsum / 8 > SOFT_STALL_MV) {
    if (++softCnt >= SOFT_STALL_SAMPLES) {
      killPwm();
      esp_timer_stop(sampleTimer);
      faults |= F_STALL_SOFT;
      lockPost(Event::Stall);
    }
  } else {
    softCnt = 0;
  }
}

static void ledcCh(ledc_channel_t ch, ledc_timer_t t, int pin, bool invert) {
  ledc_channel_config_t c = {};
  c.gpio_num = pin;
  c.speed_mode = LEDC_LOW_SPEED_MODE;
  c.channel = ch;
  c.timer_sel = t;
  c.duty = 0;
  c.flags.output_invert = invert;
  ledc_channel_config(&c);
}

void motorInit() {
  gpio_config_t out = {};
  out.pin_bit_mask = BIT64(PIN_MOTOR_PH) | BIT64(PIN_BOOST_EN);
  out.mode = GPIO_MODE_OUTPUT;
  gpio_config(&out);
  out.pin_bit_mask = BIT64(PIN_VBUS_DET);
  out.mode = GPIO_MODE_INPUT;
  gpio_config(&out);

  ledc_timer_config_t t = {};
  t.speed_mode = LEDC_LOW_SPEED_MODE;
  t.clk_cfg = LEDC_AUTO_CLK;
  t.timer_num = LEDC_TIMER_0;
  t.duty_resolution = LEDC_TIMER_10_BIT;
  t.freq_hz = 20000;
  ledc_timer_config(&t);
  t.timer_num = LEDC_TIMER_1;
  t.duty_resolution = LEDC_TIMER_14_BIT;
  t.freq_hz = 50;
  ledc_timer_config(&t);
  t.timer_num = LEDC_TIMER_2;
  t.duty_resolution = LEDC_TIMER_8_BIT;
  t.freq_hz = 5000;
  ledc_timer_config(&t);
  ledcCh(CH_MOTOR, LEDC_TIMER_0, PIN_MOTOR_EN, false);
  ledcCh(CH_SERVO, LEDC_TIMER_1, PIN_SERVO, false);
  ledcCh(CH_LED, LEDC_TIMER_2, PIN_LED, true);

  adc_oneshot_unit_init_cfg_t u = {};
  u.unit_id = ADC_UNIT_1;
  adc_oneshot_new_unit(&u, &adc);
  adc_oneshot_chan_cfg_t cc = {};
  cc.atten = ADC_ATTEN_DB_12;
  cc.bitwidth = ADC_BITWIDTH_DEFAULT;
  adc_oneshot_config_channel(adc, ADC_CHANNEL_0, &cc);
  adc_oneshot_config_channel(adc, ADC_CHANNEL_1, &cc);
  adc_cali_curve_fitting_config_t cf = {};
  cf.unit_id = ADC_UNIT_1;
  cf.atten = ADC_ATTEN_DB_12;
  cf.bitwidth = ADC_BITWIDTH_DEFAULT;
  adc_cali_create_scheme_curve_fitting(&cf, &cali);

  gpio_config_t in = {};
  in.pin_bit_mask = BIT64(PIN_NFAULT);
  in.mode = GPIO_MODE_INPUT;
  in.intr_type = GPIO_INTR_NEGEDGE;
  gpio_config(&in);
  gpio_isr_handler_add((gpio_num_t)PIN_NFAULT, faultIsr, nullptr);
  gpio_intr_disable((gpio_num_t)PIN_NFAULT);

  esp_timer_create_args_t a = {};
  a.callback = maskCb;
  a.name = "mask";
  esp_timer_create(&a, &maskTimer);
  a.callback = sampleCb;
  a.name = "ipropi";
  esp_timer_create(&a, &sampleTimer);
}

void motorRun(bool fwd) {
  setCpuFrequencyMhz(160);
  gpio_set_level((gpio_num_t)PIN_MOTOR_PH, fwd);
  memset(win, 0, sizeof win);
  wi = wsum = softCnt = 0;
  esp_timer_stop(maskTimer);
  esp_timer_stop(sampleTimer);
  portENTER_CRITICAL(&mux);
  running = true;
  gpio_intr_disable((gpio_num_t)PIN_NFAULT);
  esp_timer_start_once(maskTimer, INRUSH_MASK_US);
  portEXIT_CRITICAL(&mux);
  esp_rom_gpio_connect_out_signal(PIN_MOTOR_EN, ledc_periph_signal[0].sig_out0_idx + CH_MOTOR, false, false);
  ledc_set_duty(LEDC_LOW_SPEED_MODE, CH_MOTOR, 1 << 10);
  ledc_update_duty(LEDC_LOW_SPEED_MODE, CH_MOTOR);
}

void motorStop() {
  esp_timer_stop(maskTimer);
  esp_timer_stop(sampleTimer);
  portENTER_CRITICAL(&mux);
  running = false;
  gpio_intr_disable((gpio_num_t)PIN_NFAULT);
  REG_WRITE(GPIO_STATUS_W1TC_REG, 1u << PIN_NFAULT);
  portEXIT_CRITICAL(&mux);
  ledc_set_duty(LEDC_LOW_SPEED_MODE, CH_MOTOR, 0);
  ledc_update_duty(LEDC_LOW_SPEED_MODE, CH_MOTOR);
  killPwm();
  setCpuFrequencyMhz(80);
}

uint8_t motorFaults() { return faults; }
void motorClearFaults() { faults = 0; }

void servoSet(uint32_t us) {
  ledc_set_duty(LEDC_LOW_SPEED_MODE, CH_SERVO, us * 16384 / 20000);
  ledc_update_duty(LEDC_LOW_SPEED_MODE, CH_SERVO);
}

void boostOn() {
  if (boost) return;
  int64_t off = esp_timer_get_time() / 1000 - boostOffAt;
  if (off < BOOST_OFF_MS) vTaskDelay(pdMS_TO_TICKS(BOOST_OFF_MS - off));
  gpio_set_level((gpio_num_t)PIN_BOOST_EN, 1);
  vTaskDelay(pdMS_TO_TICKS(20));
  boost = true;
}

void boostOff() {
  ledc_set_duty(LEDC_LOW_SPEED_MODE, CH_SERVO, 0);
  ledc_update_duty(LEDC_LOW_SPEED_MODE, CH_SERVO);
  gpio_set_level((gpio_num_t)PIN_BOOST_EN, 0);
  boost = false;
  boostOffAt = esp_timer_get_time() / 1000;
}

bool vbusPresent() { return gpio_get_level((gpio_num_t)PIN_VBUS_DET); }

void ledSet(uint8_t duty) {
  ledc_set_duty(LEDC_LOW_SPEED_MODE, CH_LED, duty);
  ledc_update_duty(LEDC_LOW_SPEED_MODE, CH_LED);
}

int batteryMv() {
  int s = 0;
  for (int i = 0; i < 16; i++) s += adcMv(ADC_CHANNEL_0);
  return s * 2 / 16;
}

uint8_t batteryPct() {
  int p = (batteryMv() - 3300) * 100 / 900;
  return (uint8_t)(p < 0 ? 0 : p > 100 ? 100 : p);
}

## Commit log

2026-08-13 Template init
    [bom.csv, centroid.csv, stackup.csv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]
2026-08-13 Project init
    [bom.csv, centroid.csv, housing.scad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]
2026-08-13 3d models
    [housing.scad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]
2026-08-13 Model images
    [housing.scad]
